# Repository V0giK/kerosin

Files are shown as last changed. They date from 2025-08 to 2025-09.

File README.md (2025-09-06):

# Kerosin – RC Jet Refueling System

&#x20;
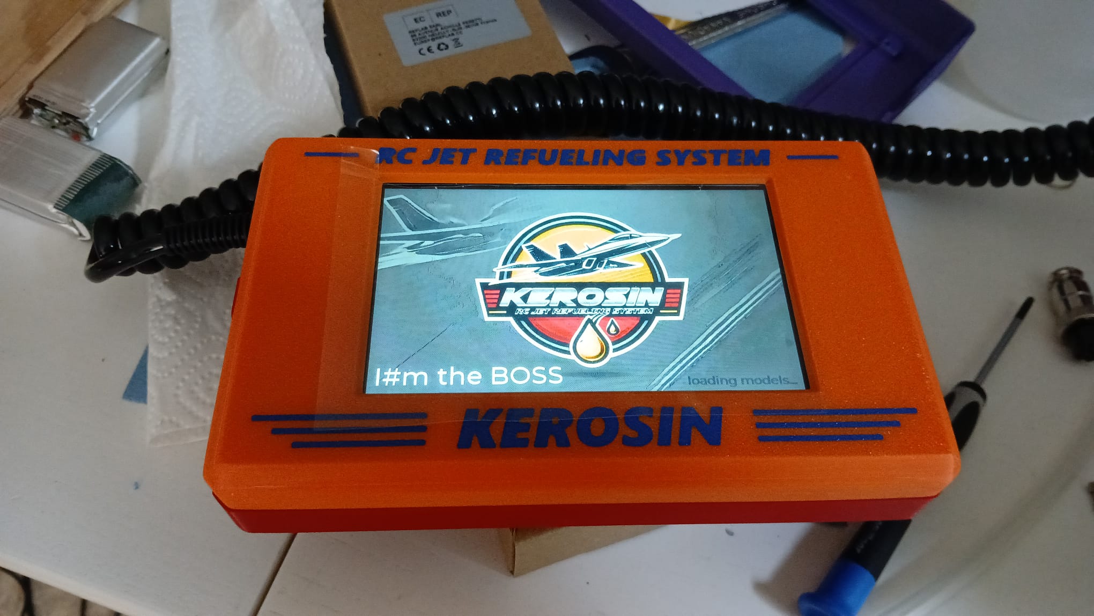
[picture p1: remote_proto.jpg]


---

## ✨ Projektübersicht

**Kerosin – RC Jet Refueling System** ist ein modulares Open-Source-System zur Betankung von Flugmodellen mit Kerosin. Es basiert auf einer Mikrocontroller-Lösung zur Überwachung und Steuerung des Tankvorgangs.

Die Steuerungseinheit ("Controller") befindet sich am Tank. Eine zweite Einheit ("Remote") mit Touchdisplay zeigt Messdaten an und löst Aktionen aus. Die Kommunikation erfolgt über RS-422.

Ziel ist eine robuste und automatisierte komfortabler Bedienung und sicherer Betankung.

---

## 🚀 Features

- **Controller (Arduino Nano)** direkt am Tank
- **Remote (ESP32)** mit Touchdisplay (JC8048W550)
- RS-422 Kommunikation (seriell)
- Automatischer Entleerungsvorgang bei Beuteltanks bei Erreichen des Abschaltdrucks
- Durchflusssensor (YF-S401) zur Kerosinerkennung beim Rückpumpen
- Drucksensor (30 psi, 1/8" NPT) zur Abschaltung
- Konfigurierbare Modelle mit individuell speicherbaren Parametern (Tanktyp, Volumen, Abschaltdruck, usw.)
- Zahnradpumpe für zuverlässige Befüllung und Rückförderung
- 3D-druckbare Komponenten & KiCad-Platinenlayout

---

## 📂 Projektstruktur

```
.
├── software/         # PlatformIO Projekte
│   ├── sTankTeil_Controller/   # Arduino Nano Code
│   └── sTankTeil_Remote/       # ESP32 Touchdisplay
├── kicad/            # KiCad-Schaltplan & Platine
├── 3d/               # 3D-Druckteile (STL, STEP)
├── LICENSE           # GPLv3 Lizenz
└── README.md         # Dieses Dokument
```

---

## 🧱 Komponenten

| Komponente | Beschreibung |
| --- | --- |
| Arduino Nano | Hauptsteuerung (am Tank) |
| ESP32 | Remote-Display (JC8048W550) |
| RS-422 Treiber | Serielle Verbindung Controller ⇄ Remote |
| Drucksensor | 30psi Sensor mit 1/8" NPT Gewinde |
| Durchflusssensor | YF-S401 zur Kerosinerkennung |
| Zahnradpumpe | Elektronisch gesteuert, rückförderfähig |

---

## 🔌 Hardwareaufbau

**Controller** ist direkt am Tank montiert und steuert:

- Drucksensor
- Durchflusssensor
- Zahnradpumpe

**Remote** zeigt Live-Daten über ein kapazitives 5.5" Touchdisplay an und erlaubt:

- Auswahl von Modellspeichern
- Anzeige von Druck, Durchfluss und der Menge des aktuellen Tankvorgangs
- Manuelle Aktionen und Steuerung

Verbindung erfolgt über abgeschirmtes RS-422-Kabel mit serieller Kommunikation.

---

## 📜 Lizenz

Dieses Projekt steht unter der [GNU General Public License v3.0](LICENSE). Jede Quellcodedatei enthält einen entsprechenden Lizenz-Header.

---

## 🤝 Mitmachen & Entwicklung

Pull Requests, Verbesserungsvorschläge oder Erweiterungen sind willkommen. Bei Fragen oder Problemen bitte [Issues](https://github.com/V0giK/kerosin/issues) verwenden.

---

## 🌍 Autor / Projekt

Entwickelt von [V0giK](https://github.com/V0giK) für RC-Tank- & Kerosinsysteme.

---

> „This is not just fuel transfer – it's controlled refueling.“

---

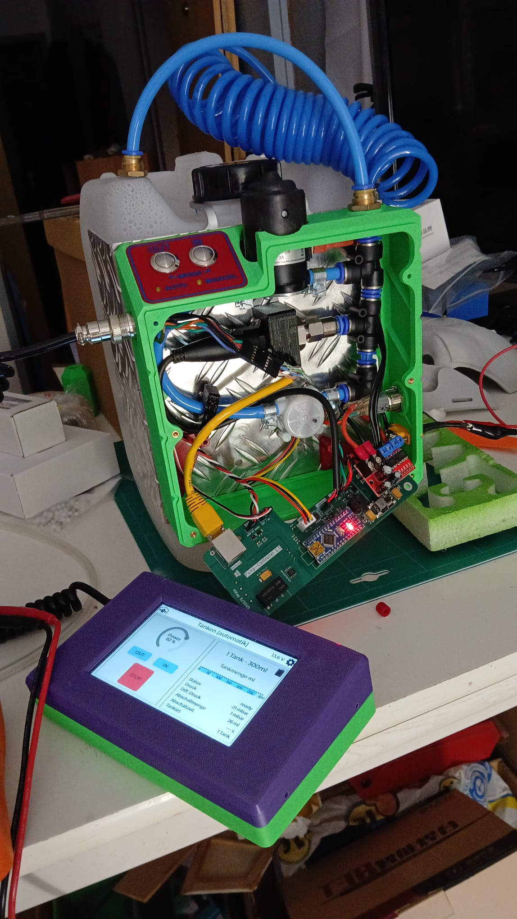
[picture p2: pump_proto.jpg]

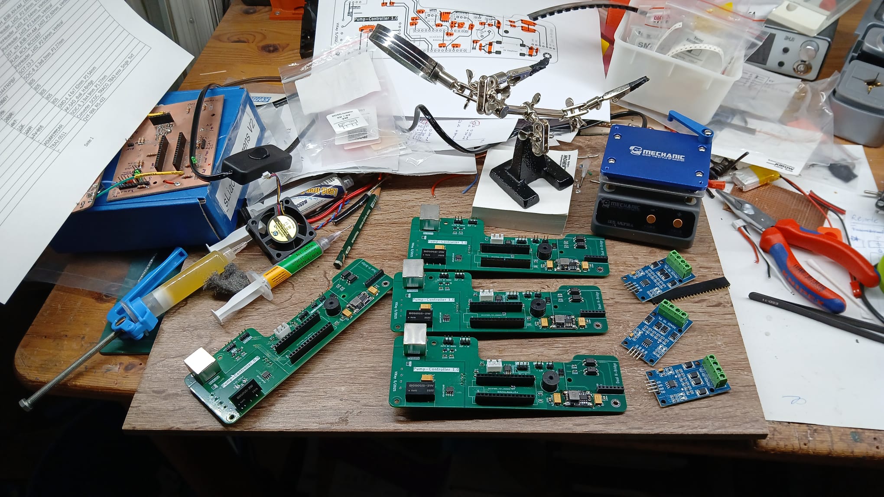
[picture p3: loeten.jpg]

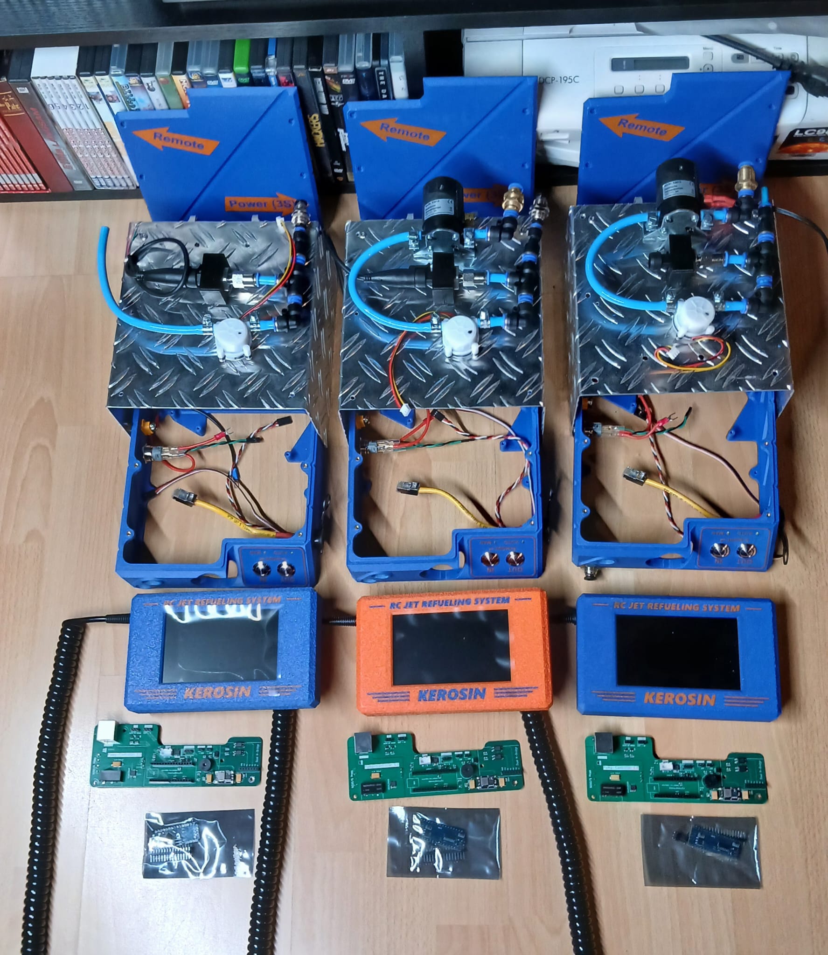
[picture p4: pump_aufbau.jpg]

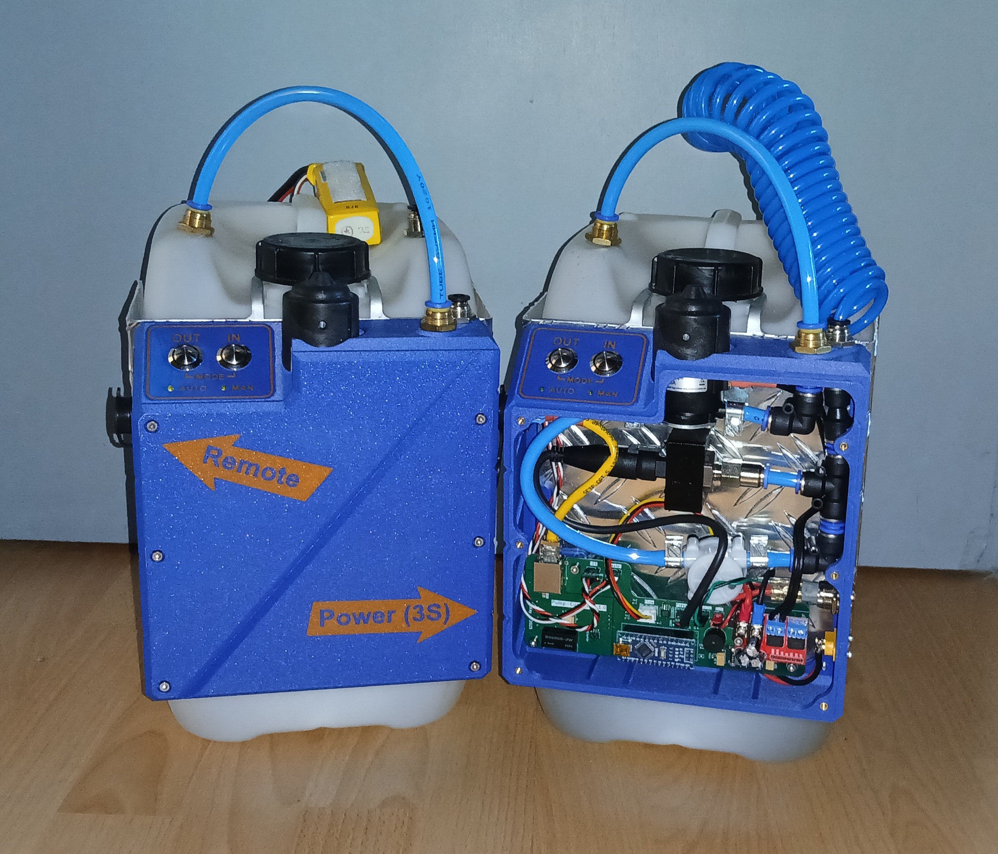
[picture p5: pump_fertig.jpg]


während des bastelns ... https://youtube.com/shorts/paOjxJlpqOs

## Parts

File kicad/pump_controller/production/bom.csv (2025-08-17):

Designator | Footprint | Quantity | Value | LCSC Part #
A1 | Arduino_Nano | 1 | Arduino_Nano_v3.x
BZ1 | Buzzer_12x9.5RM6.7 | 1 | Buzzer
C1 | CP_EIA-7343-31_Kemet-D_Pad2.25x2.55mm_HandSolder | 1 | 16V 150uF
C2, C6 | CP_EIA-7343-31_Kemet-D_Pad2.25x2.55mm_HandSolder | 2 | 6.3V 330uF
C3, C4, C5, C7 | 0805 | 4 | 100n
D3 | D_SMB_Handsoldering | 1 | SMBJ15A
D7 | D_SMA | 1 | SS34
J1 | JST_XH_B3B-XH-AM_1x03_P2.50mm_Vertical | 1 | Flow
J12 | PinHeader_1x02_P2.54mm_Vertical | 1 | LED BattLow
J13 | PinHeader_1x03_P2.54mm_Vertical | 1 | LED auto/manuel
J2 | PinHeader_1x03_P2.54mm_Vertical | 1 | Taster-In/Out
J4 | JST_XH_B3B-XH-AM_1x03_P2.50mm_Vertical | 1 | Pressure
J7 | RJ45_RCH_RC01937 | 1 | RJ45
J9 | PinHeader_1x02_P2.54mm_Vertical | 1 | Batt.
Q1, Q2, Q3, Q4, Q5, Q7 | SOT-23-3 | 6 | IRLML6344TRPBF | IRLML6344TRPBF
Q6 | SOIC-8_5.3x6.2mm_P1.27mm | 1 | SI4435DY
R1 | 0805 | 1 | 18k
R10, R11, R12, R15, R16, R17, R18, R20, R3 | 0805 | 9 | 220R
R13, R14, R5, R6, R7, R8, R9 | 0805 | 7 | 4k7
R19, R2 | 0805 | 2 | 10K
R21, R22, R4 | 0805 | 3 | 100R
U1, U2 | SMD-4_4.6x7.62mm_P2.54mm | 2 | LTV-816
U3 | AK-5AD_dual_H-Bridge | 1 | ~
U5 | SOIC-8_3.9x4.9mm_P1.27mm | 1 | ADuM1201AR
U6 | Converter_DCDC_TRACO_TBA2-xxxx_Single_THT | 1 | TBA2-0511
U7 | QYF-998_RS-422 | 1 | ~

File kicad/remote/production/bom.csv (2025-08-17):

Designator | Footprint | Quantity | Value | LCSC Part #
C1 | CP_EIA-7343-31_Kemet-D_Pad2.25x2.55mm_HandSolder | 1 | 16V 150uF
C5 | 0805 | 1 | 100n
C6 | CP_EIA-7343-31_Kemet-D_Pad2.25x2.55mm_HandSolder | 1 | 6.3V 330uF
D1 | D_SMA | 1 | SS34
D3 | D_SMB_Handsoldering | 1 | SMBJ15A
J1 | PinHeader_1x02_P2.54mm_Vertical | 1 | 5V
J2 | MPX_Adapter_small_6Pol | 1 | MPX Kabel
J3 | PinHeader_1x04_P2.54mm_Vertical | 1 | Conn_01x04_Pin
R1, R3 | R_Axial_DIN0207_L6.3mm_D2.5mm_P10.16mm_Horizontal | 2 | 10k
R2 | R_Axial_DIN0207_L6.3mm_D2.5mm_P10.16mm_Horizontal | 1 | 4k7
U1 | LevelConversion_TXB0108 | 1 | LevelConverter
U6 | TBA2-xxxx_liegend | 1 | TBA2-0511
U7 | QYF-998_RS-422 | 1 | ~

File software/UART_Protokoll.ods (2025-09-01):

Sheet: UART Action IDs
S<R/W>:<ID>:<WERT>:<CRC>
Konstante | ID |  | Wert
COM_ID_TYPE | 1 | Geräte Typ – nur lesen aus Nano (EEPROM oder #define im Code - NANO) | 1=Pumpe, 2=was anderes
COM_ID_FLOW_TICKS | 2 | Flow Ticks/Liter (EEPROM) | [1...99999]
COM_ID_PRESSURE_AVG | 3 | Anzahl Messwerte für Mittelwert Drucksensor (EEPROM) | [1...90]
COM_ID_AKKU_MIN | 4 | Akku minimal Spannung (EEPROM) | [100...119]
COM_ID_AKKU_CALIB | 5 | Akku Kalibrierfaktor (EEPROM)
COM_ID_BEEP | 6 | Signalton/Beep (EEPROM) | [0, 1]
COM_ID_SYSTEM_OFF | 7 | Systemabschaltung in Sekunden (EEPROM) | [60…550]
COM_ID_PWR_MANUEL | 8 | Pumpleistung manueller Betrieb (EEPROM) | [40…100]
COM_ID_PUMP_PWR | 9 | Pumpleistung aktuell | [40…100]
COM_ID_MAX_REFUEL_TIME | 10 | max. Betankungszeit in Sekunden | [0...350]
COM_ID_MAX_DEFUEL_TIME | 11 | max. Enttankungszeit in Sekunden | [0...350]
COM_ID_BACK_FUEL_TIME | 12 | Rücktankzeit in Sekunden | [0…60]
COM_ID_AIR_REMOVAL_TIME | 13 | Luftblasenentfernung in Sekunden | [0...30]
COM_ID_PUMP_STOP_EMPTY_DELAY | 14 | Abschaltzeit nach Leererkennung in Sekunden | [0...30]
COM_ID_MESSUREMENT_DELAY | 15 | Messverzögerung in Sekunden | [0...30]
COM_ID_MAX_REFUEL_ML | 16 | max. Tankmenge in Milliliter | [0...20990]
COM_ID_MAX_DEFUEL_ML | 17 | max. Enttankmenge in Milliliter | [0...20990]
COM_ID_MAX_PRESSURE | 18 | max. Befülldruck in mbar | [0...4990]
COM_ID_PUMP_STOP_PRESSURE_DIFF | 19 | Differenzabschaltdruck in mbar | [0...255]
COM_ID_PUMP_STOP_PRESSURE_EMPTY | 20 | Leerlaufabschaltdruck mbar | [0...255]
COM_ID_HOPPER_PRESSURE | 21 | Hopperfülldruck in mbar | [0...4990]
COM_ID_PUMP_STOP_HOPPER_PRESSURE_DIFF | 22 | Differenzabschaltdruck Hopper in mbar | [0...255]
COM_ID_PRESSURE_DROP_HOSE_BREAK | 23 | Druckabfall bei Schlauchbruch in mbar (0=Aus) | [0...255] 0=Aus
COM_ID_MODELNAME | 24 | Modellname | 15 Zeichen, es werden max 15 Zeichen in EEPROM übertragen
COM_ID_SAVE_MODEL_EEPROM | 29 | Modelldaten in EEPROM schreiben für Verwendung ohne Remote | ‘5‘ als Value immer 5 mitgeben
COM_ID_STATUS | 30 | Status | Ready, Tanken, Entlüften, …
COM_ID_CURRENT_ML | 31 | Momentane Tankmenge in Milliliter
COM_ID_CURRENT_MBAR | 32 | Momentaner Tankdruck in mbar
COM_ID_CURRENT_DIFF_MBAR | 33 | Differenzdruck in mbar
COM_ID_AKKU_VOLT | 34 | Akkuspannung | beim senden als Kallibrierungsspannung an Controller 1111 = 11.11
COM_ID_PUMP_CONTROL | 40 | Pumpe steuern | [0...2] 0=Enttanken, 1=Tanken, 2=STOP
COM_ID_WRITE_EEPROM | 41 | Controller – Daten in EEPROM schreiben (EEPROM) | ‘5‘ als Value immer 5 mitgeben
COM_ID_PUMP_MODE | 42 | Pumpen Mode | [0...2] 0=manuell, 1=auto, 2=kalib. Flow, 3=kalib. Model
COM_ID_FLOWCALIBRATE | 43 | aktuelle Flowticks seit letztem Reset | [0...99999]
COM_ID_TANKTYPE | 44 | Tanktyp | [0...2] 0=Beutel, 1=1 Tank, 2=2 Tanks
COM_ID_BROADCAST | 45 | Daten per Broadcast senden (dauernd) | [0...1] 0=nein, 1=ja
COM_ID_FIRMWARE_VERSION | 46 | Firmware Version abfragen | 1.0.0‘
COM_ID_MC_RESET | 99 | Mikrocontroller reset | 99=DeepSleep

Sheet: Button IDs
Button Ids
ID | Button | Panel (Screen)
1 | Reset | Flowsensor kalibrierung | BTN_FLOW_RESET
2 | Set – Flow | Flowsensor kalibrierung | BTN_FLOW_SET
3 | Reset | Modell – Anzahl Tankvorgänge | BTN_MODEL_RESET_TANKCOUNT
4 | Reset | Modell – Gesamtmenge | BTN_MODEL_RESET_TOTAL
5 | Modell löschen | Modell – löschen | BTN_MODEL_DELETE
6 | Modell speichern JA | Modelle – neu/bearbeiten | BTN_MODEL_SAVE_YES
7 | Modell speichern NEIN | Modelle – neu/bearbeiten | BTN_MODEL_SAVE_NO
8 | System speichern JA | Systemeinstellungen bearbeiten | BTN_SYSTEM_SAVE_YES
9 | System speichern NEIN | Systemeinstellungen bearbeiten | BTN_SYSTEM_SAVE_NO
10 | Save Modeldata in Controller | Modell – Tanken/Pumpen | BTN_MODEL_SAVE2CONTROLLER
11 | Header-Titel longPress |  | BTN_HEADER_TITEL_LONGPRESS
12 | Stop Snake |  | BTN_SNAKE_STOP
13 | Tanktype geändert | Modell – Settings | BTN_MODEL_TYPE_CHG
14 | gemessene Spannung senden | Systemeinstellungen bearbeiten | BTN_SYSTEM_SEND_CALIBVOLT
15 | WiFi starten (Backup/OTA) | Systemeinstellungen bearbeiten | BTN_SYSTEM_BACKUP

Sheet: Nano Pins
NANO Pins
PIN | Verwendung |  | Pull-Up/Down
A0 | Batt. Spannung messen
A1 | LED model |  | Pull-up | 4,7 kΩ
A2 | LED manuel |  | Pull-up | 4,7 kΩ
A3 | LED Batt. Low |  | Pull-up | 4,7 kΩ
A4 | SDA | I2C | Pull-up | 4,7 kΩ
A5 | SCL | I2C | Pull-up | 4,7 kΩ
A6 | Druck Sensor |  | Pull-down | 4,7 kΩ
A7
D2 | Flow Sensor |  | Pull-up | 4,7 kΩ
D3 | LED ERROR | PWM | Pull-up | 4,7 kΩ
D4 | Buzzer
D5 | H-Bridge D2 | PWM
D6 | H-Bridge D3 | PWM
D7 | Taster-In |  | Pull-up | 4,7 kΩ
D8 | Taster-Out |  | Pull-up | 4,7 kΩ
D9 |  | PWM
D10 | SoftSerial TX | PWM | Pull-up
D11 | SoftSerial RX | PWM | Pull-up
D12 | remote check |  | Pull-up | 4,7 kΩ
D13 | ready LED | Built-in LED | Pull-up | ?

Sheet: Modell Parameter
 |  |  |  | Tanktyp
Konstante | Hide Variable | Beschreibung | Default | Beutel | 1 Tank | 2Tanks
COM_ID_MODELNAME | bHideModModelname | Modell |  | X | X | X
COM_ID_TANKTYPE |  | Tanktyp | 0 = Beutel | X | X | X
COM_ID_PUMP_PWR |  | Pumpleistung [%] | 81 | X | X | X
COM_ID_PRESSURE_DROP_HOSE_BREAK |  | Druckabfall bei Schlauchbruch [mbar] (0=Aus) | 0 | X | X | X | 0 = deaktiviert
COM_ID_MAX_REFUEL_TIME |  | Maximale Betankzeit [s] | 240 | X | X | X | 0 = deaktiviert
COM_ID_MAX_DEFUEL_TIME |  | Maximale Enttankzeit [s] | 240 | X | X | X | 0 = deaktiviert
COM_ID_BACK_FUEL_TIME |  | Rücktankzeit [s] | 6 | X | X | X | 0 = deaktiviert
COM_ID_AIR_REMOVAL_TIME |  | Luftblasenentfernung [s] | 15 | X Nachdem Unterdruck > Leerlaufabschaltdruck |  |  | 0 = deaktiviert
COM_ID_PUMP_STOP_EMPTY_DELAY |  | Abschaltzeit nach Leererkennung [s] | 5 (Beutel bei Speicher auf 0) |  | X | X | 0 = deaktiviert
COM_ID_MESSUREMENT_DELAY |  | Messverzögerung [s] | 5 | X | X | X | 0 = deaktiviert
COM_ID_MAX_REFUEL_ML |  | Maximale Betankmenge [ml] | 500 | X | X | X | 0 = deaktiviert
COM_ID_MAX_DEFUEL_ML |  | Maximale Enttankmenge [ml] | 500 | X | X | X | 0 = deaktiviert
COM_ID_MAX_PRESSURE |  | Maximaler Tankdruck [mbar] | 350 | X | X | X | 0 = deaktiviert
COM_ID_PUMP_STOP_PRESSURE_DIFF |  | Differenzabschaltdruck [mbar] | 19 |  | X | X | 0 = deaktiviert
COM_ID_PUMP_STOP_PRESSURE_EMPTY |  | Leerlaufabschaltdruck [mbar] | 187 | X Unterdruck < Leerlaufdruck DiffDruck == 0 FlowRate <= 1 ml/s | X | X | 0 = deaktiviert
COM_ID_HOPPER_PRESSURE |  | Maximaler Hopperfülldruck [mbar] | 400 |  |  | X | 0 = deaktiviert
COM_ID_PUMP_STOP_HOPPER_PRESSURE_DIFF |  | Differenzabschaltdruck Hopper [mbar] | 19 |  |  | X | 0 = deaktiviert
 |  | Letzte Tankmege [ml] | 0 | X | X | X
 |  | Tankvorgänge | 0 | X | X | X
 |  | Gesamttankmenge [L] | 0 | X | X | X

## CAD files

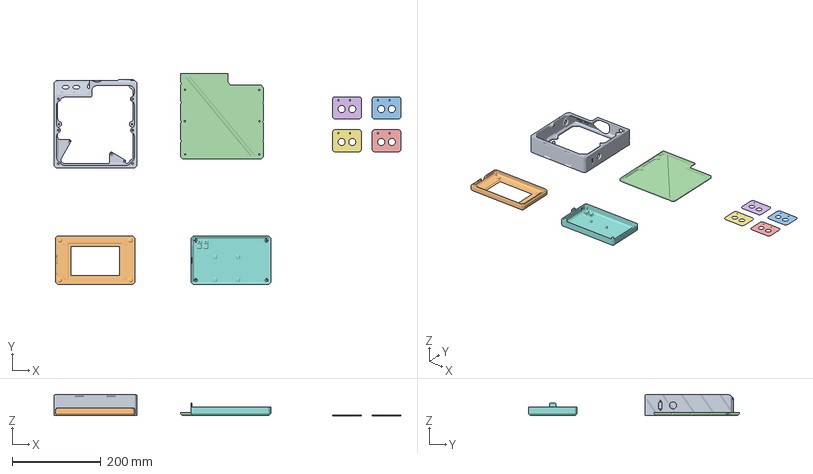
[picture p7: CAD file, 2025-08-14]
3d/Gehäuse_Pumpe v5.3mf
784.2 x 476.9 x 48.5 mm
Gehäuse_Frame.stl
Remote_Deckel.stl
Panel.stl x 4
Gehäuse_Deckel.stl
Remote_Boden.stl

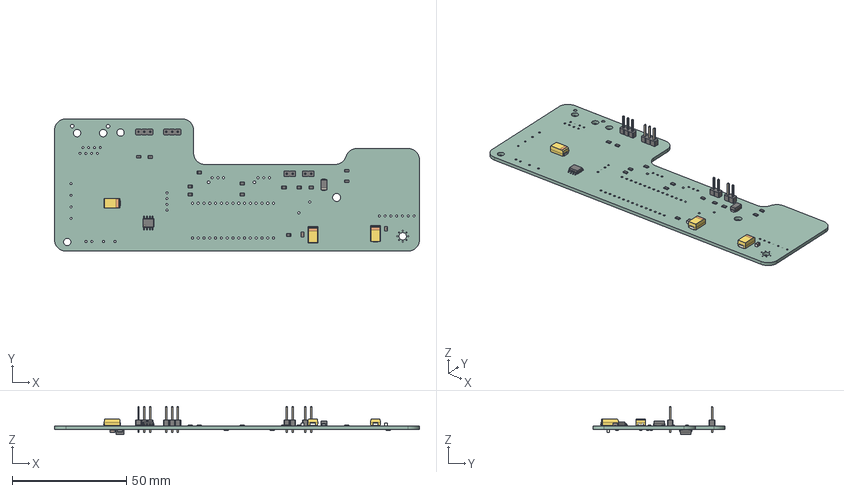
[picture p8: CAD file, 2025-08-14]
kicad/pump_controller/pump_controller.step
160.0 x 58.0 x 12.4 mm
PinHeader_1x02_P2.54mm_Vertical x 2
PinHeader_1x03_P2.54mm_Vertical x 2
R_0805_2012Metric x 17
SOIC-8_3.9x4.9mm_P1.27mm
CP_EIA-7343-31_Kemet-D x 3
C_0805_2012Metric x 3
D_SMA
D_SMB
pump_controller_PCB

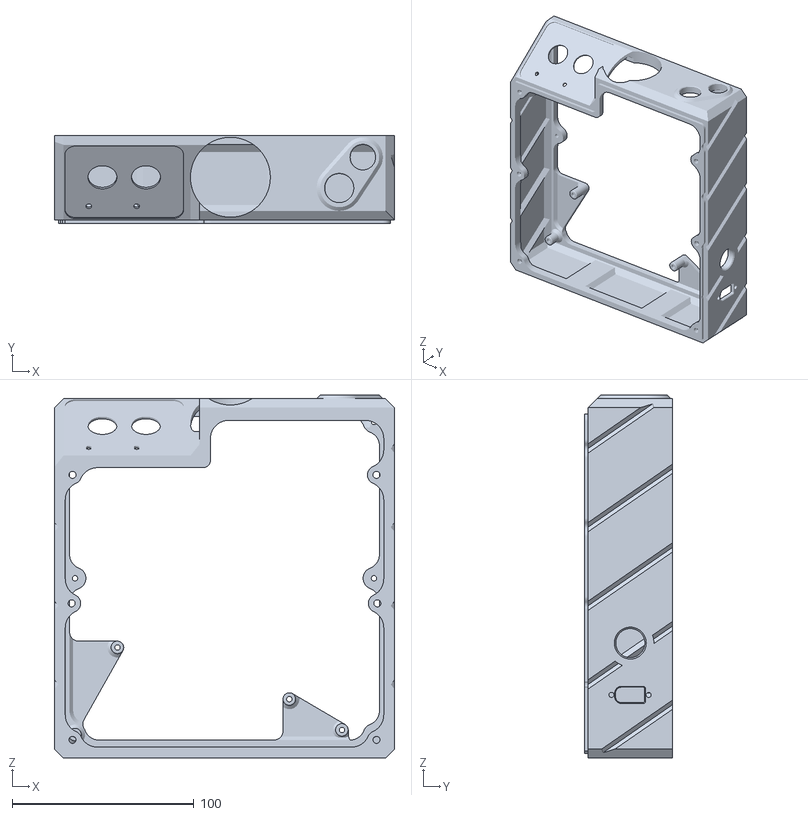
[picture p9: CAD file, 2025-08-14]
3d/Gehäuse_Frame.stl
187.5 x 48.5 x 200.0

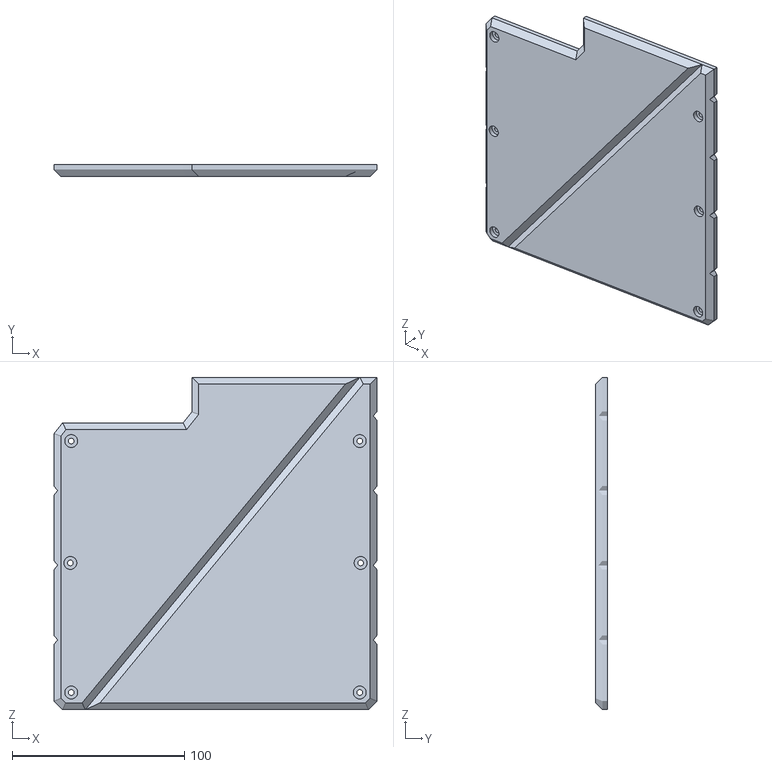
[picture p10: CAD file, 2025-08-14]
3d/Gehäuse_Deckel.stl
187.5 x 7.00 x 193.0

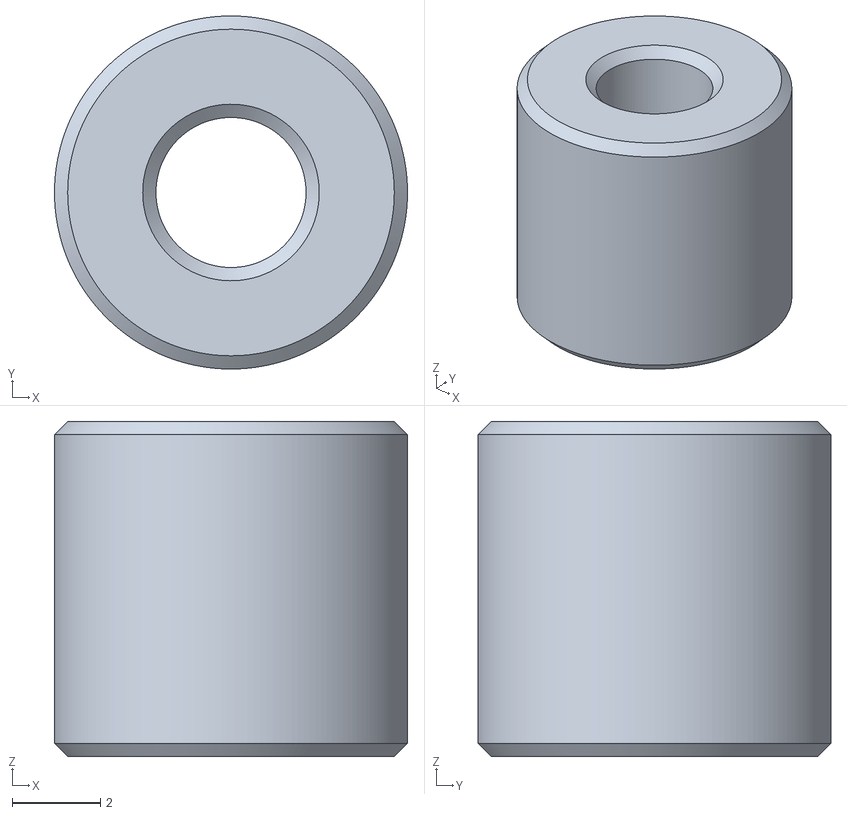
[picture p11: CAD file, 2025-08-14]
3d/Huelse.stl
8.00 x 8.00 x 7.60

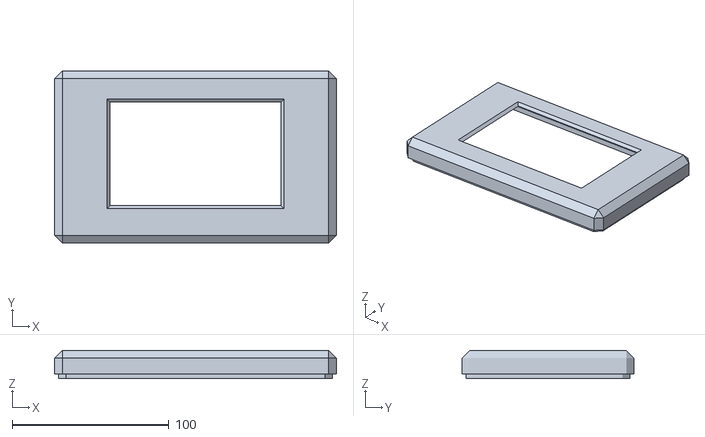
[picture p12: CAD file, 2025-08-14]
3d/Remote_Deckel.stl
180.0 x 110.0 x 18.0

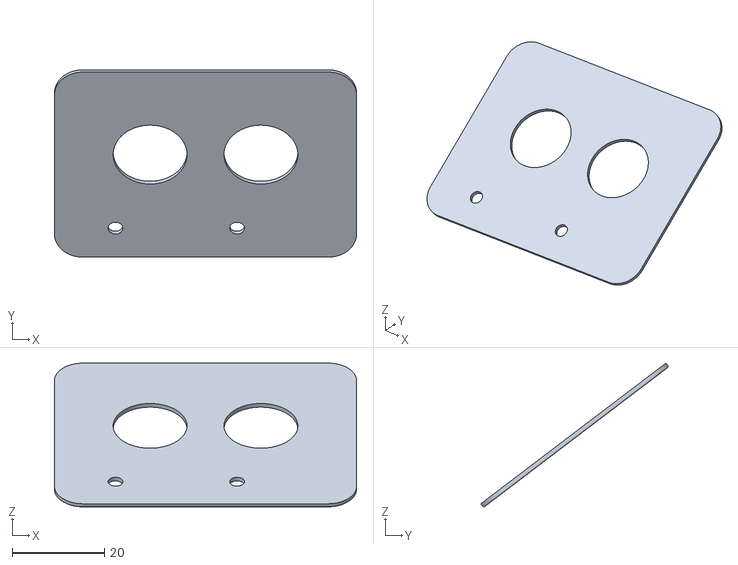
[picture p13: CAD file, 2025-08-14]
3d/Panel.stl
65.4 x 40.6 x 31.1

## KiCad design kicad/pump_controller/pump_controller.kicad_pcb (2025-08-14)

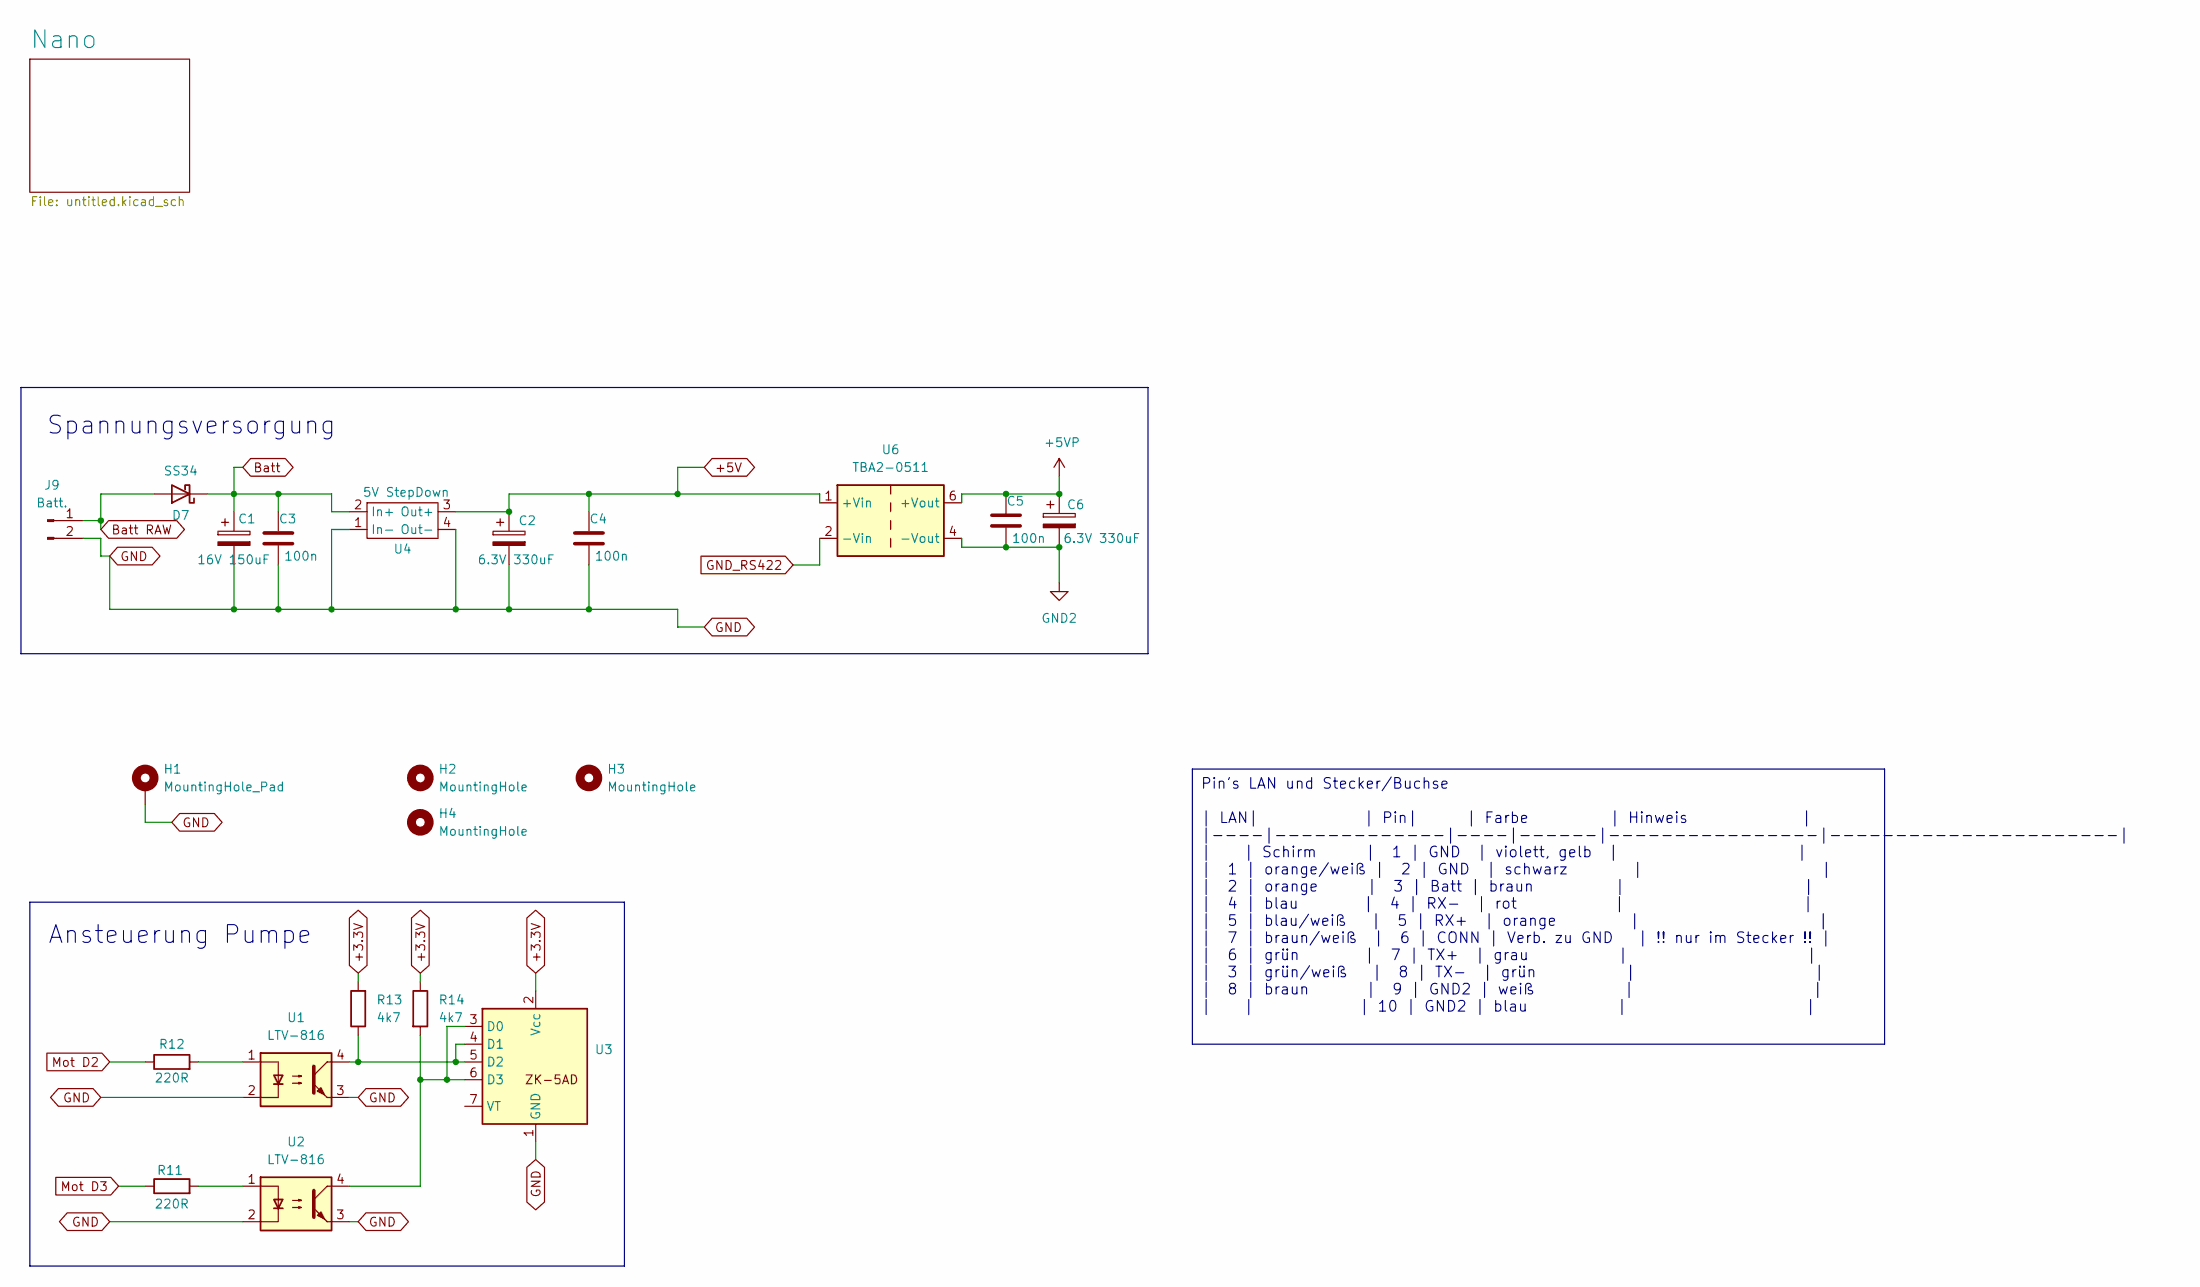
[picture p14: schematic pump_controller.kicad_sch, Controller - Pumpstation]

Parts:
C1: 16V 150uF; CP_EIA-7343-31_Kemet-D_Pad2.25x2.55mm_HandSolder
C2, C6: 6.3V 330uF; CP_EIA-7343-31_Kemet-D_Pad2.25x2.55mm_HandSolder
C3, C4, C5: 100n; C_0805_2012Metric_Pad1.18x1.45mm_HandSolder
D7: SS34; D_SMA
H1: MountingHole_Pad; MountingHole_3.2mm_M3_Pad_Via
H2, H4: MountingHole; MountingHole_3.2mm_M3_ISO7380
H3: MountingHole; MountingHole_3.5mm
J9: Batt.; PinHeader_1x02_P2.54mm_Vertical
R11, R12: 220R; R_0805_2012Metric_Pad1.20x1.40mm_HandSolder
R13, R14: 4k7; R_0805_2012Metric_Pad1.20x1.40mm_HandSolder
U1, U2: LTV-816; SMD-4_4.6x7.62mm_P2.54mm
U3: AK-5AD_dual_H-Bridge
U4: 5V StepDown; Step-Down 5V
U6: TBA2-0511; Converter_DCDC_TRACO_TBA2-xxxx_Single_THT

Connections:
+3.3V: R13.2, R14.1, U3.2 (Vcc)
+5V: C2.1, C4.1, U4.3 (Out+), U6.1 (+Vin); also elsewhere on the board
+5VP: C5.1, C6.1, U6.6 (+Vout); also elsewhere on the board
Batt: C1.1, C3.1, D7.1 (K), U4.2 (In+); also elsewhere on the board
Batt RAW: D7.2 (A), J9.1
GND: C1.2, C2.2, C3.2, C4.2, H1.1, J9.2, U1.2, U1.3, U2.2, U2.3, U3.1 (GND), U4.1 (In-), U4.4 (Out-); also elsewhere on the board
GND2: C5.2, C6.2, U6.4 (-Vout); also elsewhere on the board
GND_RS422: U6.2 (-Vin); also elsewhere on the board
Mot D2: R12.1; also elsewhere on the board
Mot D3: R11.1; also elsewhere on the board
unnamed: R11.2, U2.1
unnamed: R12.2, U1.1
unnamed: R14.2, U2.4, U3.3 (D0), U3.6 (D3)
unnamed: R13.1, U1.4, U3.4 (D1), U3.5 (D2)

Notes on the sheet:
Spannungsversorgung
Ansteuerung Pumpe
Pin's LAN und Stecker/Buchse | LAN| | Pin| | Farbe | Hinweis | |----|-------------|----|------|----------------|----------------------| | | Schirm | 1 | GND | violett, gelb | | | 1 | orange/weiß | 2 | GND | schwarz | | | 2 | orange | 3 | Batt | braun | | | 4 | blau | 4 | RX- | rot | | | 5 | blau/we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

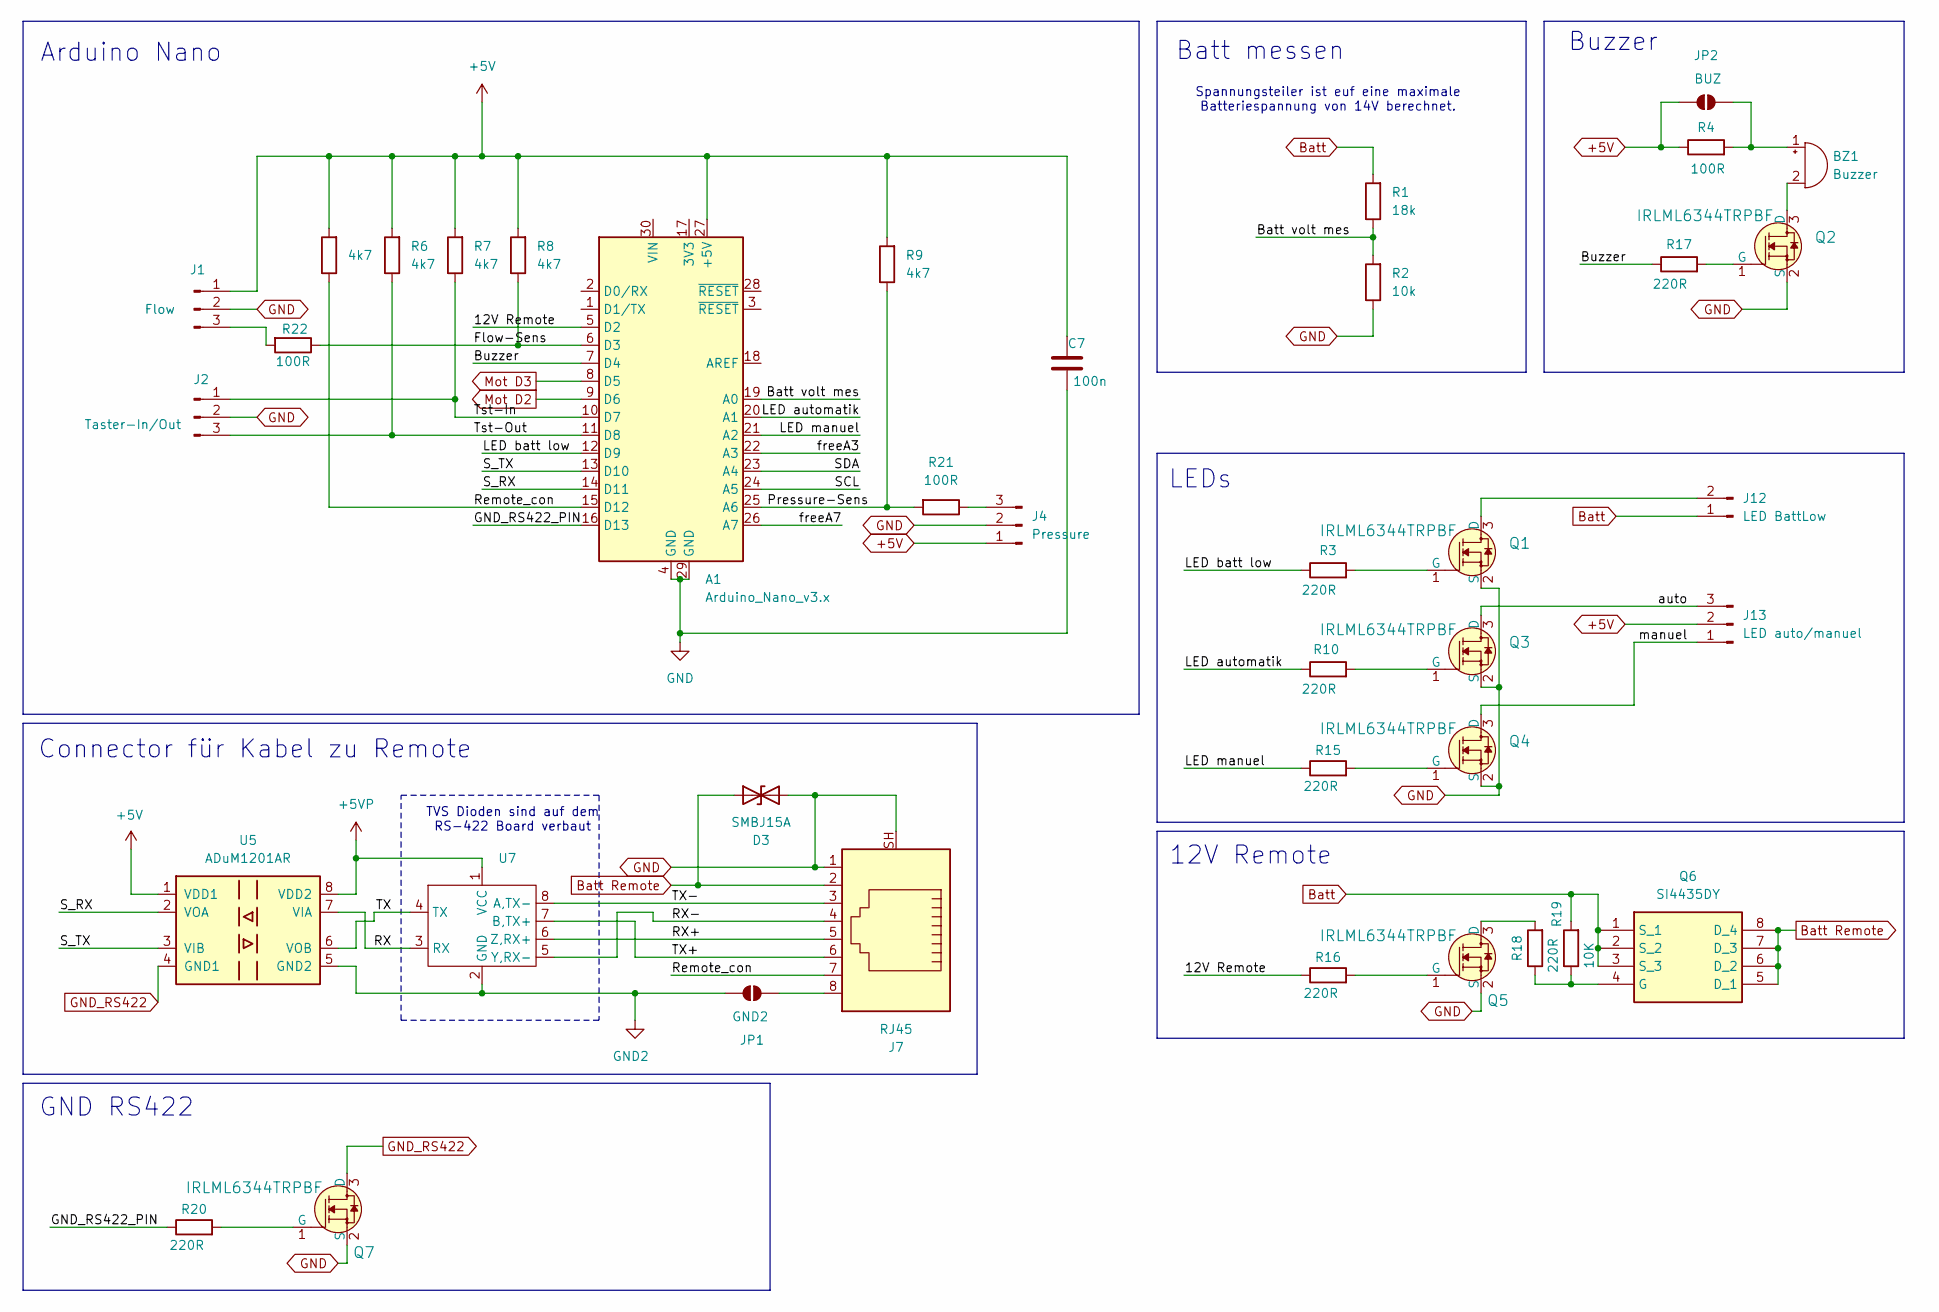
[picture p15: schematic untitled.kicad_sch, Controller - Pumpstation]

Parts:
A1: Arduino_Nano_v3.x; Arduino_Nano
BZ1: Buzzer; Buzzer_12x9.5RM6.7
C7: 100n; C_0805_2012Metric_Pad1.18x1.45mm_HandSolder
D3: SMBJ15A; D_SMB_Handsoldering
J1: Flow; JST_XH_B3B-XH-AM_1x03_P2.50mm_Vertical
J2: Taster-In/Out; PinHeader_1x03_P2.54mm_Vertical
J4: Pressure; JST_XH_B3B-XH-AM_1x03_P2.50mm_Vertical
J7: RJ45; RJ45_RCH_RC01937
J12: LED BattLow; PinHeader_1x02_P2.54mm_Vertical
J13: LED auto/manuel; PinHeader_1x03_P2.54mm_Vertical
JP1: GND2; SolderJumper-2_P1.3mm_Open_Pad1.0x1.5mm
JP2: BUZ; SolderJumper-2_P1.3mm_Open_Pad1.0x1.5mm
Q1, Q2, Q3, Q4, Q5, Q7: IRLML6344TRPBF; SOT-23-3; MPN IRLML6344TRPBF; Digi-Key_PN IRLML6344TRPBFCT-ND
Q6: SI4435DY; SOIC-8_5.3x6.2mm_P1.27mm; Mouser Part Number 512-SI4435DY
R1: 18k; R_0805_2012Metric_Pad1.20x1.40mm_HandSolder
R2: 10k; R_0805_2012Metric_Pad1.20x1.40mm_HandSolder
R3, R10, R15, R16, R17, R18, R20: 220R; R_0805_2012Metric_Pad1.20x1.40mm_HandSolder
R4, R21, R22: 100R; R_0805_2012Metric_Pad1.20x1.40mm_HandSolder
R5, R6, R7, R8, R9: 4k7; R_0805_2012Metric_Pad1.20x1.40mm_HandSolder
R19: 10K; R_0805_2012Metric_Pad1.20x1.40mm_HandSolder
U5: ADuM1201AR; SOIC-8_3.9x4.9mm_P1.27mm
U7: QYF-998_RS-422

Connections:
+5V: A1.27 (+5V), C7.1, J1.1, J4.1, J13.2, JP2.2 (B), R4.1, R5.2, R6.2, R7.2, R8.2, R9.2, U5.1 (VDD1); also elsewhere on the board
+5VP: U5.8 (VDD2), U7.1 (VCC); also elsewhere on the board
/Nano/12V Remote: A1.5 (D2), R16.1
/Nano/Batt volt mes: A1.19 (A0), R1.1, R2.2
/Nano/Buzzer: A1.7 (D4), R17.1
/Nano/Flow-Sens: A1.6 (D3), R8.1, R22.1
/Nano/GND_RS422_PIN: A1.16 (D13), R20.1
/Nano/LED automatik: A1.20 (A1), R10.1
/Nano/LED batt low: A1.12 (D9), R3.1
/Nano/LED manuel: A1.21 (A2), R15.1
/Nano/Pressure-Sens: A1.25 (A6), R9.1, R21.2
/Nano/RX: U5.7 (VIA), U7.3 (RX)
/Nano/RX+: J7.4, U7.5 (Y)
/Nano/RX-: J7.5, U7.6 (Z)
/Nano/Remote_con: A1.15 (D12), J7.7, R5.1
/Nano/SCL: A1.24 (A5)
/Nano/SDA: A1.23 (A4)
/Nano/S_RX: A1.14 (D11), U5.2 (VOA)
/Nano/S_TX: A1.13 (D10), U5.3 (VIB)
/Nano/TX: U5.6 (VOB), U7.4 (TX)
/Nano/TX+: J7.6, U7.7 (B)
/Nano/TX-: J7.3, U7.8 (A)
/Nano/Tst-In: A1.10 (D7), J2.1, R7.1
/Nano/Tst-Out: A1.11 (D8), J2.3, R6.1
/Nano/auto: J13.3, Q3.3 (D)
/Nano/freeA3: A1.22 (A3)
/Nano/freeA7: A1.26 (A7)
/Nano/manuel: J13.1, Q4.3 (D)
Batt: J12.1, Q6.1 (S_1), Q6.2 (S_2), Q6.3 (S_3), R1.2, R19.2; also elsewhere on the board
Batt Remote: D3.1 (A1), J7.2, Q6.5 (D_1), Q6.6 (D_2), Q6.7 (D_3), Q6.8 (D_4)
GND: A1.4 (GND), A1.29 (GND), C7.2, D3.2 (A2), J1.2, J2.2, J4.2, J7.1, J7.SH, Q1.2 (S), Q2.2 (S), Q3.2 (S), Q4.2 (S), Q5.2 (S), Q7.2 (S), R2.1; also elsewhere on the board
GND2: JP1.1 (A), U5.5 (GND2), U7.2 (GND); also elsewhere on the board
GND_RS422: Q7.3 (D), U5.4 (GND1); also elsewhere on the board
Mot D2: A1.9 (D6); also elsewhere on the board
Mot D3: A1.8 (D5); also elsewhere on the board
unnamed: BZ1.1 (+), JP2.1 (A), R4.2
unnamed: BZ1.2 (-), Q2.3 (D)
unnamed: J1.3, R22.2
unnamed: J4.3, R21.1
unnamed: J12.2, Q1.3 (D)
unnamed: J7.8, JP1.2 (B)
unnamed: Q1.1 (G), R3.2
unnamed: Q2.1 (G), R17.2
unnamed: Q3.1 (G), R10.2
unnamed: Q4.1 (G), R15.2
unnamed: Q5.3 (D), R18.2
unnamed: Q5.1 (G), R16.2
unnamed: Q6.4 (G), R18.1, R19.1
unnamed: Q7.1 (G), R20.2

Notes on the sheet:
Buzzer
GND RS422
12V Remote
LEDs
Spannungsteiler ist euf eine maximale Batteriespannung von 14V berechnet.
TVS Dioden sind auf dem RS-422 Board verbaut
Batt messen
Arduino Nano
Connector für Kabel zu Remote

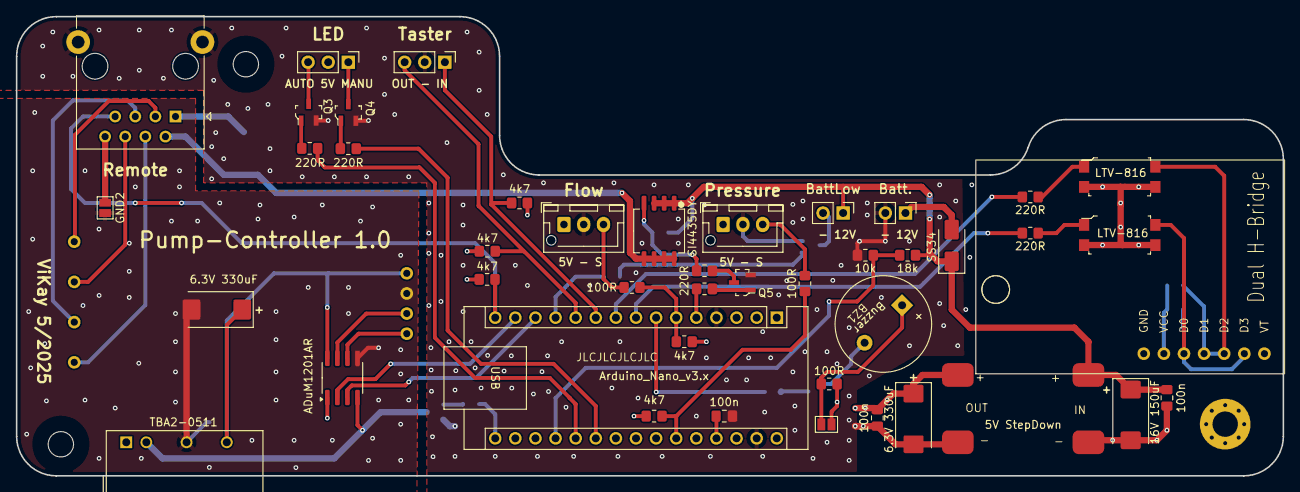
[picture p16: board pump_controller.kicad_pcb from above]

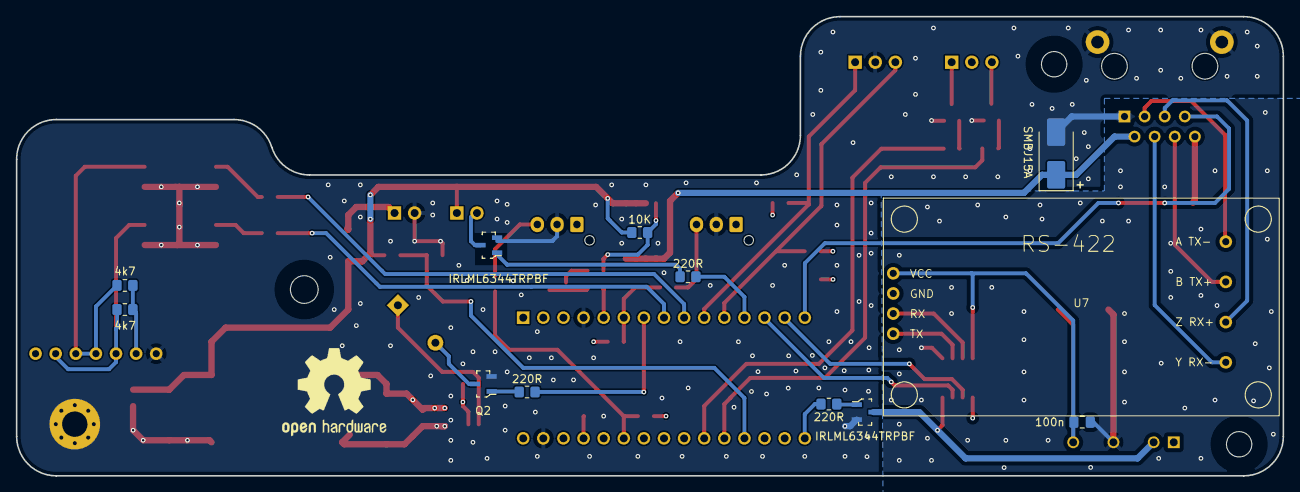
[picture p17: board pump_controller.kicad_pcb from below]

Board: 4 copper layers, 160.0 x 58.0 mm, 60 parts (12 on the bottom side), 51 nets.

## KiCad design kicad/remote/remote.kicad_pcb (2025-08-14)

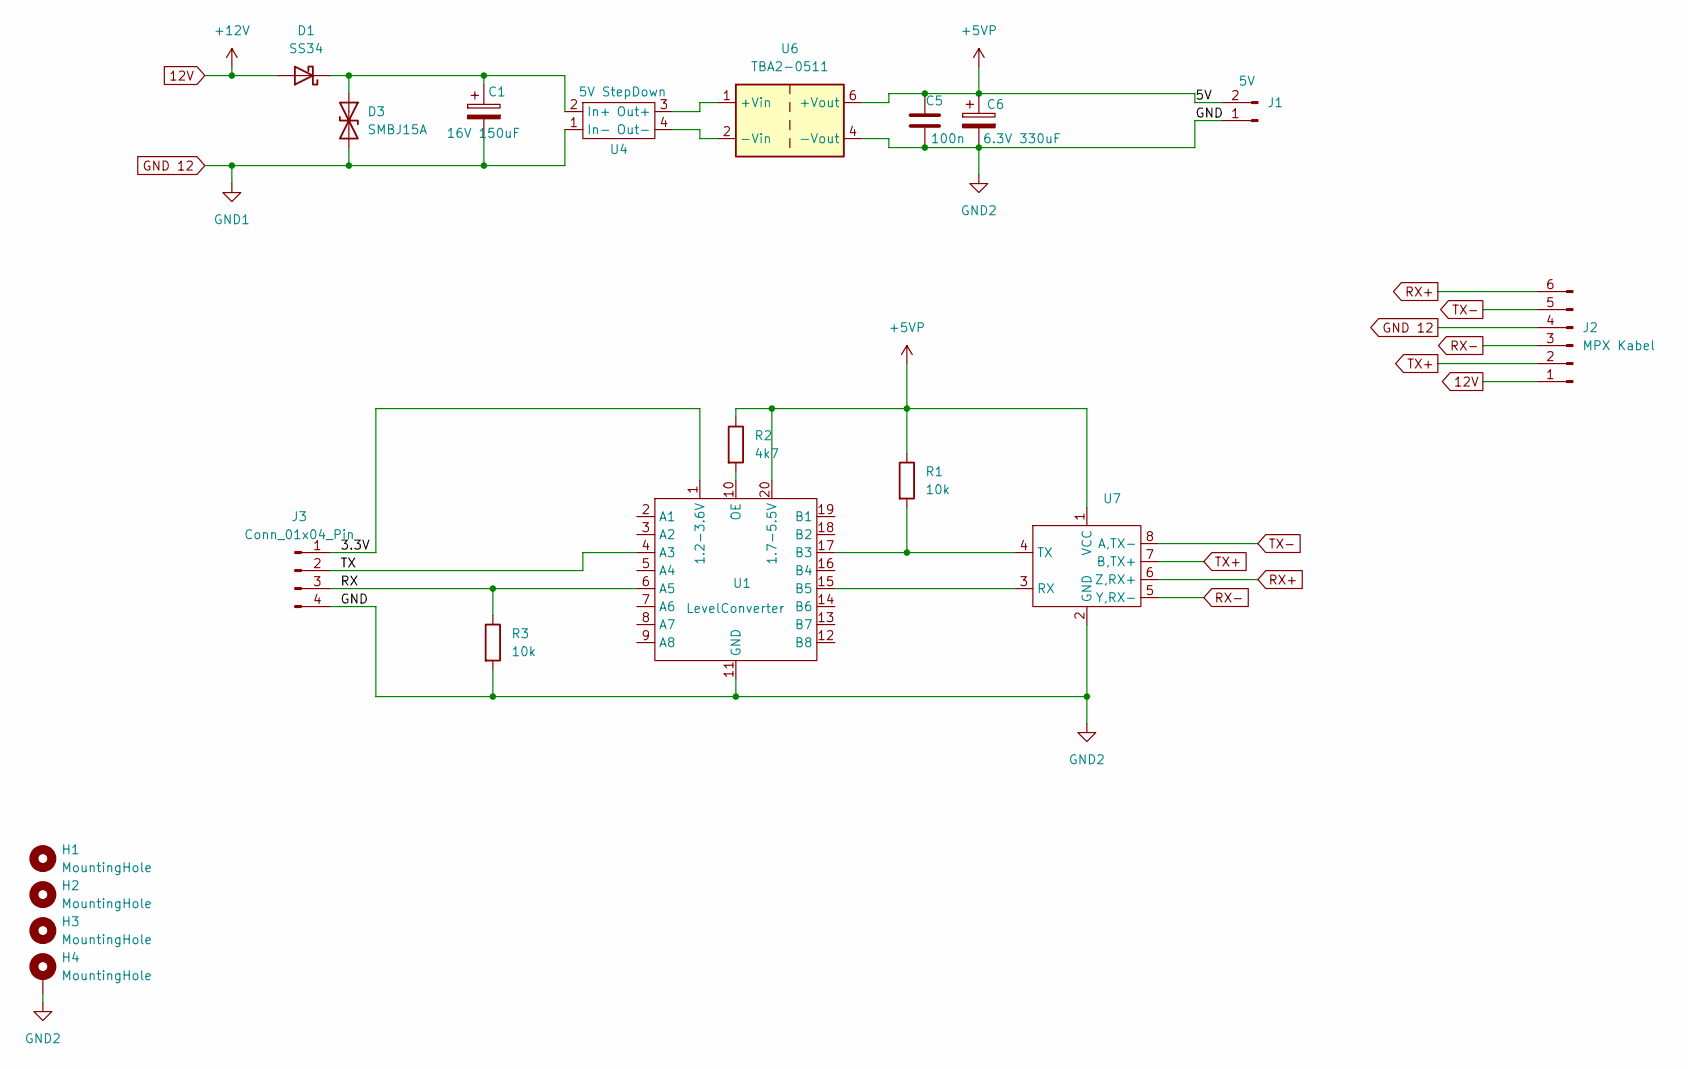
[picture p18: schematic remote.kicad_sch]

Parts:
C1: 16V 150uF; CP_EIA-7343-31_Kemet-D_Pad2.25x2.55mm_HandSolder
C5: 100n; C_0805_2012Metric_Pad1.18x1.45mm_HandSolder
C6: 6.3V 330uF; CP_EIA-7343-31_Kemet-D_Pad2.25x2.55mm_HandSolder
D1: SS34; D_SMA
D3: SMBJ15A; D_SMB_Handsoldering
H1, H2, H3: MountingHole; MountingHole_3.2mm_M3_ISO7380
H4: MountingHole; MountingHole_3.2mm_M3_Pad_Via
J1: 5V; PinHeader_1x02_P2.54mm_Vertical
J2: MPX Kabel; MPX_Adapter_small_6Pol
J3: Conn_01x04_Pin; PinHeader_1x04_P2.54mm_Vertical
R1, R3: 10k; R_Axial_DIN0207_L6.3mm_D2.5mm_P10.16mm_Horizontal
R2: 4k7; R_Axial_DIN0207_L6.3mm_D2.5mm_P10.16mm_Horizontal
U1: LevelConverter; LevelConversion_TXB0108
U4: 5V StepDown; Step-Down 5V
U6: TBA2-0511; TBA2-xxxx_liegend
U7: QYF-998_RS-422

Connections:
12V: D1.2 (A), J2.1
+5VP: C5.1, C6.1, J1.2, R1.1, R2.1, U1.20 (1.7-5.5V), U6.6 (+Vout), U7.1 (VCC)
/3.3V: J3.1, U1.1 (1.2-3.6V)
/RX: J3.3, R3.1, U1.6 (A5)
/TX: J3.2, U1.4 (A3)
GND2: C5.2, C6.2, H4.1, J1.1, J3.4, R3.2, U1.11 (GND), U6.4 (-Vout), U7.2 (GND)
GND 12: C1.2, D3.2 (A2), J2.4, U4.1 (In-)
unnamed: C1.1, D1.1 (K), D3.1 (A1), U4.2 (In+)
unnamed: R1.2, U1.17 (B3), U7.4 (TX)
unnamed: U1.15 (B5), U7.3 (RX)
unnamed: R2.2, U1.10 (OE)
unnamed: U4.3 (Out+), U6.1 (+Vin)
unnamed: U4.4 (Out-), U6.2 (-Vin)
RX+: J2.6, U7.6 (Z,RX+)
RX-: J2.3, U7.5 (Y,RX-)
TX+: J2.2, U7.7 (B,TX+)
TX-: J2.5, U7.8 (A,TX-)

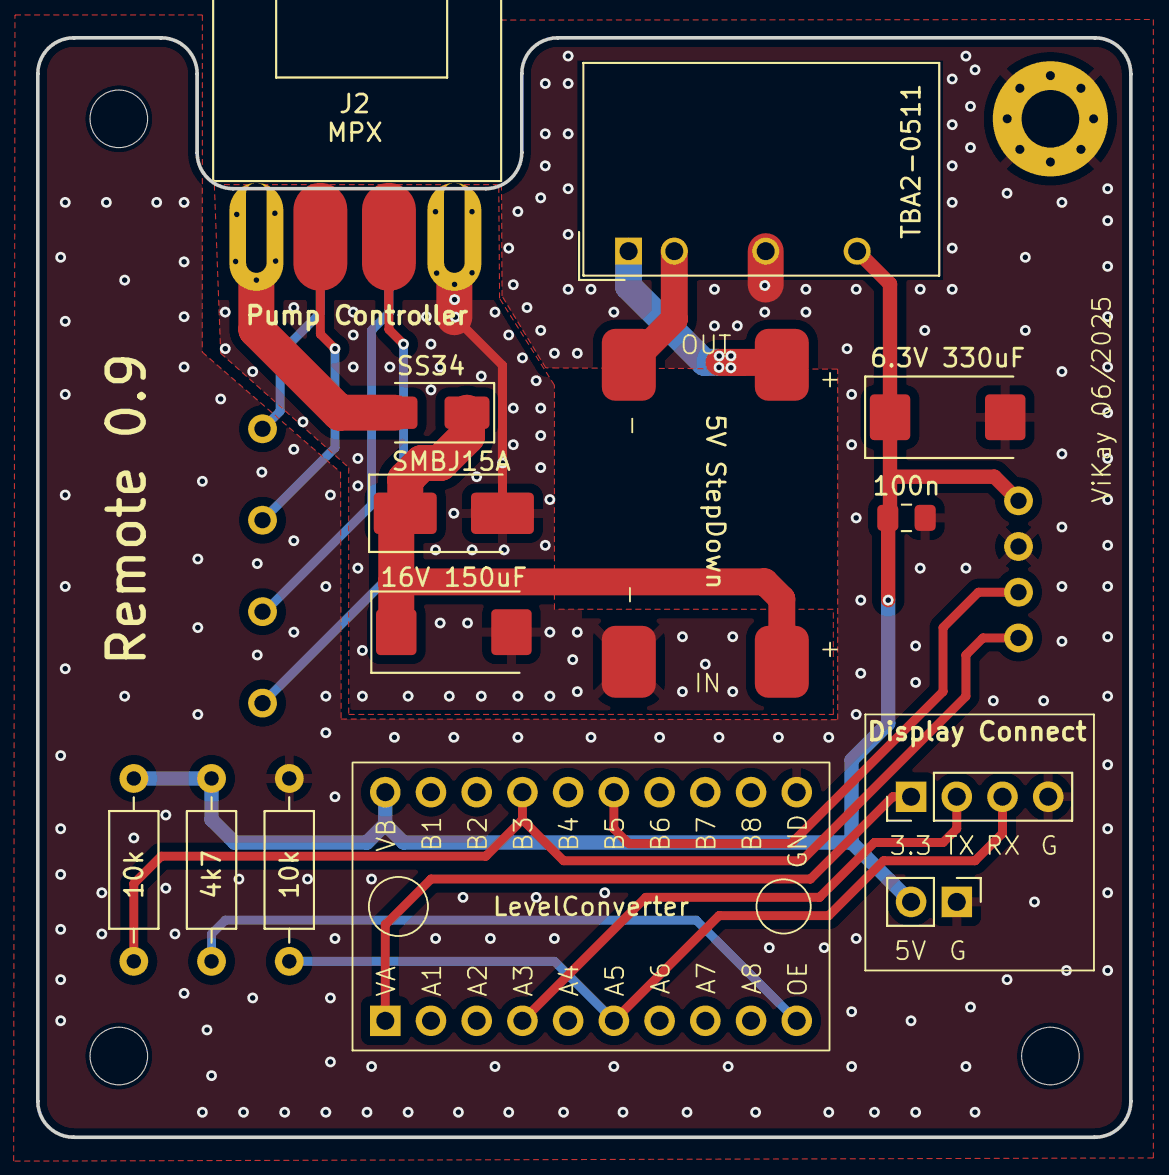
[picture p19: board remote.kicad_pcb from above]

Board: 2 copper layers, 60.7 x 61.1 mm, 19 parts (1 on the bottom side), 17 nets.

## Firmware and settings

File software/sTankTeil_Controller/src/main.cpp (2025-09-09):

/*
 * Hauptprogramm zur Steuerung einer Arduino-basierten Tanklösung
 *
 * Copyright (C) 2025 V0giK
 *
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
 * You should have received a copy of the GNU General Public License
 * along with this program.  If not, see <https://www.gnu.org/licenses/>.
 */

 #include <Arduino.h>

#include "variables.h"
#include "defines.h"
#include "main.h"
#include "bufferFunctions.h"
#include "pumpFunctions.h"


// Batteriespannung Warnungen - Callback-Funktion
void voltageAlert(const char* message, unsigned long duration) {
    // Serial.print(message);
    // Serial.print(" for ");
    // Serial.print(duration);
    // Serial.println(" seconds");

    if(strcmp(message, "warning") == 0) {
      if(duration >= 5) {
        buzzer.playBatteryLowTone();
        ledController.startLowBatteryBlinking();
      }

    } else {
      if(duration >= 5) {
        buzzer.playBatteryEmptyTone();
        ledController.startErrorBlinking();
        if(!(pump.isOn() || pumpSeq.isProcessing()) && bRemoteConnected) {
          // TODO: Spannung abschalten!!!!!
          //Serial.println("Power OFF.  empty battery");
          remoteCom.sendData('W', COM_ID_MC_RESET, "99", true);
          // delay(50);
          // resetFunc();
          // enterSleepNano();
        }
      } else {
        buzzer.playBatteryLowTone();
        ledController.stopLowBatteryBlinking();
      }
    }
}


void setup() {

  pinMode(PIN_LED_MODEL, OUTPUT);   // LED model
  pinMode(PIN_LED_MANUEL, OUTPUT);  // LED manuel
  // pinMode(PIN_LED_BATT, OUTPUT);    // LED batt. low
  pinMode(PIN_MOTE_TXRX, OUTPUT);
  digitalWrite(PIN_MOTE_TXRX, LOW);
  pinMode(PIN_MOTE_12V, OUTPUT);
  digitalWrite(PIN_MOTE_12V, LOW);

  // {
    // Serial.println("Lösche EEPROM...");
    // // EEPROM löschen
    // for (int i = 0; i < EEPROM.length(); i++) {
    //     EEPROM.write(i, 0xFF); // 0xFF entspricht einem leeren Wert
    // }
    // Serial.println("EEPROM wurde geleert.");
    // return;
  // }

  //configManager.resetToDefaults();

    #ifdef DEBUG
    Serial.begin(115200);        // Serielle Schnittstelle starten
    #endif
    // Callbacks registrieren
    remoteCom.setWriteCallback(onWrite);
    remoteCom.setReadCallback(onRead);

    bRemoteConnected = !digitalRead(PIN_MOTE_CHK);
    #ifdef DEBUG
    Serial.print("Remote connected (PIN_MOTE_CHK="); Serial.print(bRemoteConnected?"true":"false"); Serial.println(")");
    //Serial.flush();
    #endif

    if(bRemoteConnected) {
      digitalWrite(PIN_MOTE_TXRX, HIGH); // Versorgungsspannung für Kommunikation mit Remote aktivieren (RS422)
      digitalWrite(PIN_MOTE_12V, HIGH); // Versorgungsspannung für Remote aktivieren (12V)
      remoteCom.begin(9600);              // 19200 Serielle Schnittstelle mit der Remote initialisieren

    } else {
      buttonManager.begin(); // Initialisierung der Taster
      // Callbacks setzen
      buttonManager.onButtonInClick(onButtonInClick);
      buttonManager.onButtonOutClick(onButtonOutClick);
      buttonManager.onBothButtonsLongPress(onBothButtonsLongPress);

      // Modelldaten aus EEPROM lesen - falls vorhanden
      // Start immer im "Modell-Mode", ausser es sind keine Daten vorhanden ... dies auch beim Mode-Wechsel berücksichtigen!!!!!
      bHasModelSaved = model.loadFromEEPROM(EEPROM_ADR_MODEL);
      if(bHasModelSaved) {
        fifo_input_buffer.push(getRecDataObj(COM_ID_PUMP_MODE, "1")); // MODE_AUTO
      } else {
        // model.setTankType(0); // TankType initialisieren da laufend darauf geprüft wird
        fifo_input_buffer.push(getRecDataObj(COM_ID_PUMP_MODE, "0")); // MODE_MANUELL
      }
    }

    buzzer.begin(); // Buzzer initialisieren

    // Konfiguration laden
    configManager.loadConfig();
    buzzer.setReminderSeconds(configManager.getSystemabschaltungSekunden());
    buzzer.setActive(configManager.getSignaltonOn());

    // Durchflusssensor initialisieren
    flowSensor.begin();
    flowSensor.setCalibration(configManager.getImpulseProLiter());
    // Drucksensor initialisieren
    pressureSensor.setNumSamples(configManager.getAnzahlMesswerteMittelwert());
    pressureSensor.calibSensor();

    // Akkuspannung initialisieren
    // TODO: Wert fehlt noch im EEPROM !!!!!!!!!!!!!!!!!
    // voltReader.setCalibrationFactor(2.9183);
    voltReader.setCalibrationFactor(configManager.getBattKalibrierungsfaktor() / 10000.0);
    voltReader.setThresholds(configManager.getMinimalspannungAkku() / 10.0, 9.5, voltageAlert);

    #ifdef DEBUG
    Serial.println("System gestartet...");
    //Serial.flush();
    #endif


    // LEDs prüfen
    digitalWrite(PIN_LED_MODEL, HIGH);
    digitalWrite(PIN_LED_MANUEL, HIGH);
    digitalWrite(PIN_LED_BATT, HIGH);
    delay(1500);
    digitalWrite(PIN_LED_MODEL, LOW);
    digitalWrite(PIN_LED_MANUEL, LOW);
    digitalWrite(PIN_LED_BATT, LOW);

    pinMode(PIN_MOTE_CHK, INPUT);
    // pinMode(PIN_TASTER_IN, INPUT);
    // pinMode(PIN_TASTER_OUT, INPUT);


    // ESP32 (Remote) neu starten
    remoteCom.sendData('W', COM_ID_MC_RESET, "");

    buzzer.playAcknowledgmentTone();
}

void loop() {
  bool hasActivity = false;

  if(pump.isOn() || pumpSeq.isProcessing()) hasActivity = true;
  hasActivity |= remoteCom.tick();  // Remote prüfen
  buttonManager.update();           // Taster-Logik aktualisieren
  hasActivity |= buffer_tick();     // Eingangs-Puffer verarbeiten

  if(hasActivity) buzzer.updateActivity();
  buzzer.checkReminder();

  // Berechne die Spannung
  voltReader.readVoltage();
  // LED-Status aktualisieren
  ledController.update();


  unsigned long currentMillis = millis();
  if (currentMillis - lastMillis >= MEASUREMENT_INTERVAL) {
      lastMillis = currentMillis;
      bHalfIntervall = false;

      handleFlowMeasurement();     // Durchflussmessung
      handlePressureMeasurement(); // Druckmessung
      handlePumpSeq();

  }
  if (!bHalfIntervall && currentMillis - lastMillis >= MEASUREMENT_INTERVAL / 2) {
    bHalfIntervall = true;

    // Durchflussrate und Gesamtmenge berechnen
    if(pumpMode != MODE_CALIB_FLOW){
      flowSensor.tick();
    }
    // Druck abfragen
    pressureSensor.tick();

    // Remote an/ausgesteckt
    if(!digitalRead(PIN_MOTE_CHK) != bRemoteConnected) {
      resetNano();
    }

  }

  // 5 Sekunden
  if (currentMillis - lastMillis5sec >= INTERVAL_5S) {
    lastMillis5sec = currentMillis;
    // Batteriespannung prüfen
    voltReader.evaluateVoltage(); // Bewertung der Spannung und ggf. Callback-Aufruf
    remoteCom.sendData('W', COM_ID_AKKU_VOLT, voltReader.getLastVoltageString().c_str());

  }

}



// Durchflussmessung durchführen
void handleFlowMeasurement() {
  if(pump.isOn() || bSendBroadcast) {
    switch(pumpMode) {
      case MODE_CALIB_FLOW:
        // TODO
        remoteCom.sendData('W', COM_ID_FLOWCALIBRATE, String(flowSensor.getPulses()).c_str());
        return;
        break;
      // case MODE_AUTO:
      // case MODE_CALIB_MODEL:
      // case MODE_MANUELL:
      default:
        break;
    }

    // UART-Daten senden
    remoteCom.sendData('W', COM_ID_CURRENT_ML, String(flowSensor.getTotalMilliliters()).c_str());

    // Debug-Ausgabe
    // if (DEBUG) {
    //   Serial.print("Durchflussrate: ");
    //   Serial.print(flowSensor.getFlowRate());
    //   Serial.print(" ml/s, Gesamtmenge: ");
    //   Serial.print(flowSensor.getTotalMilliliters());
    //   Serial.println(" ml");
    // }

  }
}

// Druckmessung durchführen
void handlePressureMeasurement() {

  double pressure_mbar = floor(pressureSensor.getPressureMbar(true));
  double pressure_diff = floor(pressureSensor.getDiffMbar());
  if(pump.isOn() || bSendBroadcast) {
    remoteCom.sendData('W', COM_ID_CURRENT_MBAR, String(pressure_mbar).c_str());
    remoteCom.sendData('W', COM_ID_CURRENT_DIFF_MBAR, String(pressure_diff).c_str());

    // Debug-Ausgabe
    // if (DEBUG) {
    //     Serial.print("Druck: ");
    //     Serial.print(pressure_mbar, 2);
    //     Serial.print(" mbar, Diff: ");
    //     Serial.print(pressure_diff, 2);
    //     Serial.println(" mbar");
    // }
  }

}

// Callback für SW (Schreiben)
void onWrite(int16_t id, const String &value) {
  // if (DEBUG) Serial.println("SW erhalten: ID=" + String(id) + ", Wert=" + value);

  recData dta = getRecDataObj(id, value);
  // in Input-Puffer schreiben
  fifo_input_buffer.push(dta);
}

// Callback für SR (Lesen)
void onRead(int16_t id) {
  // if (DEBUG) Serial.println("SR erhalten: ID=" + String(id));

  bool hasActivity = true;
  switch (id) {
    case COM_ID_TYPE:
      remoteCom.sendData('W', id, HARDWARE_TYPE);
      break;
    case COM_ID_FLOW_TICKS:
      remoteCom.sendData('W', id, String(configManager.getImpulseProLiter()).c_str());
      break;
    case COM_ID_PRESSURE_AVG:
      remoteCom.sendData('W', id, String(configManager.getAnzahlMesswerteMittelwert()).c_str());
      break;
    case COM_ID_AKKU_MIN:
      remoteCom.sendData('W', id, String(configManager.getMinimalspannungAkku()).c_str());
      break;
    case COM_ID_AKKU_CALIB:
      remoteCom.sendData('W', id, String(configManager.getBattKalibrierungsfaktor()).c_str());
      break;
    case COM_ID_BEEP:
      remoteCom.sendData('W', id, String(configManager.getSignaltonOn()).c_str());
      break;
    case COM_ID_PWR_MANUEL:
      remoteCom.sendData('W', id, String(configManager.getManuellePumpenleistung()).c_str());
      break;
    case COM_ID_SYSTEM_OFF:
      remoteCom.sendData('W', id, String(configManager.getSystemabschaltungSekunden()).c_str());
      break;
    case COM_ID_FIRMWARE_VERSION:
      remoteCom.sendData('W', id, SW_VERSION);
      break;
    default:
      //
      hasActivity = false;
      break;
  }

  if(hasActivity) buzzer.updateActivity();
}




void handlePumpSeq() {
  refuellAction();
  backfuellAction();
  defuellAction();
  airremovalAction();
}






// Callback-Funktionen definieren
void onButtonInClick() {
  buzzer.playAcknowledgmentTone();
  if(pump.isOn()) {
    fifo_input_buffer.push(getRecDataObj(COM_ID_PUMP_CONTROL, "2")); // CTR_STOP
  } else {
    fifo_input_buffer.push(getRecDataObj(COM_ID_PUMP_CONTROL, "1")); // CTR_TANKEN
  }
}

void onButtonOutClick() {
  buzzer.playAcknowledgmentTone();
  if(pump.isOn()) {
    fifo_input_buffer.push(getRecDataObj(COM_ID_PUMP_CONTROL, "2")); // CTR_STOP
  } else {
    fifo_input_buffer.push(getRecDataObj(COM_ID_PUMP_CONTROL, "0")); // CTR_ENTTANKEN
  }
}

void onBothButtonsLongPress() {
  buzzer.playAcknowledgmentTone();
  if(pump.isOn()) {
    fifo_input_buffer.push(getRecDataObj(COM_ID_PUMP_CONTROL, "2")); // CTR_STOP
  }
  if(bHasModelSaved && pumpMode == MODE_MANUELL) {
    fifo_input_buffer.push(getRecDataObj(COM_ID_PUMP_MODE, "1")); // MODE_AUTO
  } else {
    if(!bHasModelSaved) buzzer.playNegativeTone();
    fifo_input_buffer.push(getRecDataObj(COM_ID_PUMP_MODE, "0")); // MODE_MANUELL
  }
}

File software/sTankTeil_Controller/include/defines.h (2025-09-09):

/*
 * Hauptprogramm zur Steuerung einer Arduino-basierten Tanklösung
 *
 * Copyright (C) 2025 V0giK
 *
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
 * You should have received a copy of the GNU General Public License
 * along with this program.  If not, see <https://www.gnu.org/licenses/>.
 */

#pragma once

// 16 Bit
#define INT_BIT_LENGTH 15

// prüfen/ setzen des ACK Bit's für die Srrielle Kommunikation
#define isacki(value) (((value) >> (INT_BIT_LENGTH)) & 0x01)
#define acki(value) ((value) |= (1UL << (INT_BIT_LENGTH)))
#define nacki(value) ((value) &= ~(1UL << (INT_BIT_LENGTH)))
#define setacki(value, wack) ((wack)?(acki(value)):(nacki(value)))
#define clracki(value) ((nacki(value)))


#define TYPE_PUMP "1"

#define HARDWARE_TYPE TYPE_PUMP

#define PIN_MOTE_12V 2
#define PIN_MOTE_TXRX 13
#define PIN_SOFT_RX 11
#define PIN_SOFT_TX 10

#define PIN_PUMP_D0 5
#define PIN_PUMP_D1 6

#define PIN_FLOW 3
#define PIN_PRESSURE A6

#define PIN_BATT_MESURE A0
#define PIN_LED_MODEL   A1
#define PIN_LED_MANUEL  A2
#define PIN_LED_BATT    9
#define PIN_TASTER_IN   7
#define PIN_TASTER_OUT  8
#define PIN_MOTE_CHK    12
#define PIN_BUZZER 4


// UART Nachrichten IDs
#define COM_ID_TYPE                           1
#define COM_ID_FLOW_TICKS                     2
#define COM_ID_PRESSURE_AVG                   3
#define COM_ID_AKKU_MIN                       4
#define COM_ID_AKKU_CALIB                     5
#define COM_ID_BEEP                           6
#define COM_ID_SYSTEM_OFF                     7
#define COM_ID_PWR_MANUEL                     8
#define COM_ID_PUMP_PWR                       9
#define COM_ID_MAX_REFUEL_TIME                10
#define COM_ID_MAX_DEFUEL_TIME                11
#define COM_ID_BACK_FUEL_TIME                 12
#define COM_ID_AIR_REMOVAL_TIME               13
#define COM_ID_PUMP_STOP_EMPTY_DELAY          14
#define COM_ID_MESSUREMENT_DELAY              15
#define COM_ID_MAX_REFUEL_ML                  16
#define COM_ID_MAX_DEFUEL_ML                  17
#define COM_ID_MAX_PRESSURE                   18
#define COM_ID_PUMP_STOP_PRESSURE_DIFF        19
#define COM_ID_PUMP_STOP_PRESSURE_EMPTY       20
#define COM_ID_HOPPER_PRESSURE                21
#define COM_ID_PUMP_STOP_HOPPER_PRESSURE_DIFF 22
#define COM_ID_PRESSURE_DROP_HOSE_BREAK       23

#define COM_ID_SAVE_MODEL_EEPROM              29

#define COM_ID_STATUS                         30
#define COM_ID_CURRENT_ML                     31
#define COM_ID_CURRENT_MBAR                   32
#define COM_ID_CURRENT_DIFF_MBAR              33
#define COM_ID_AKKU_VOLT                      34

#define COM_ID_PUMP_CONTROL                   40
#define COM_ID_WRITE_EEPROM                   41
#define COM_ID_PUMP_MODE                      42
#define COM_ID_FLOWCALIBRATE                  43
#define COM_ID_TANKTYPE                       44
#define COM_ID_BROADCAST                      45
#define COM_ID_FIRMWARE_VERSION               46

#define COM_ID_MC_RESET                       99

// Pumpmodes
#define MODE_MANUELL     0
#define MODE_AUTO        1
#define MODE_CALIB_FLOW  2
#define MODE_CALIB_MODEL 3

// Tanktype
#define TANK_BEUTEL 0
#define TANK_1TANK  1
#define TANK_2TANK  2

// Pumpaktionen
#define CTR_ENTTANKEN 0
#define CTR_TANKEN    1
#define CTR_STOP      2


//
#define REFUELL_BEUTEL     "1,2,1,4"
#define DEFUELL_BEUTEL     "3"
#define REFUELL_1TANK      "1,4"
#define DEFUELL_1TANK      "3"
#define REFUELL_2TANKS     "1,5,4"
#define DEFUELL_2TANKS     "3"

#define SW_VERSION "1.0.1"

// Debug switch für compile-time
// #define DEBUG

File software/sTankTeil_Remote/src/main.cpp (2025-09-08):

/*
 * Hauptprogramm zur Steuerung einer Arduino-basierten Tanklösung
 *
 * Copyright (C) 2025 V0giK
 *
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
 * You should have received a copy of the GNU General Public License
 * along with this program.  If not, see <https://www.gnu.org/licenses/>.
 */

#include <Arduino.h>
#include <ArduinoJson.h>
#include <LittleFS.h>  // Für den Dateizugriff
#include "main.h"
// #include <lvgl.h>
// #include "lovyanGfxSetup.h"
#include "ui/ui.h"
#include "ui/vars.h"
#include "ui/styles.h"
#include "ui/actions.h"
#include "helper.h"
#include "uartCommunication.h"
#include "modelParameters.h"
#include "snakeGame.h"
#include "aeroBlocks.h"  // Include the AeroBlocks header
#include <esp_task_wdt.h>
#include "configManager.h" // Include the config manager
#include "modelManager.h" // Include the model manager
#include "controllerUtils.h" // Include the controller utility functions
#include "uiHandlers.h" // <--- Neues Include für die ausgelagerte Funktion
#include "displayConfig.h" // LVGL Display-Konfiguration
#include "pumpControl.h" // Pumpensteuerung
#include "inputHandlers.h" // Neue Includes für die Input Handler
#include <WiFi.h>
#include <esp_bt.h>

// Konstanten für optimale Timing-Intervalle
const uint32_t UART_CHECK_INTERVAL = 10;     // 100Hz für UART
const uint32_t UI_UPDATE_INTERVAL = 20;      // 50Hz für Display
const uint32_t STATUS_CHECK_INTERVAL = 1000; // 1Hz für System Status
const uint32_t WDT_TIMEOUT = 5;              // 5s Watchdog

// Timing Variablen
static uint32_t lastUartCheck = 0;
static uint32_t lastUiUpdate = 0;
static uint32_t lastStatusCheck = 0;

// Debug-Ausgabe steuern
const bool DEBUG = false;
//LV_LOG_USER("dfg");

// Setup constants
const int UI_UPDATE_ITERATIONS = 5;
const int MODEL_JSON_DOC_SIZE = 1024;  // Increased from 512 to 1024 bytes to handle larger model files
const int SETUP_DISPLAY_DELAY = 100;  // ms

// Display
LGFX tft;

extern lv_event_t g_keyboardShowE;
extern lv_event_t g_numpadShowE;
extern lv_event_t g_go2settingsModelsE;
extern lv_event_t g_resetDataFieldsE;
extern lv_event_t g_go2modelE;
extern lv_event_t g_go2calibrateModelE;
extern lv_event_t g_eventButtonClickE;
extern lv_event_t g_changePumpPwrE;
extern lv_event_t g_go2newModelE;


// Define the global variables that replace the bit fields for the undefined references
// Note: Some flags are now in the UIFlags union - separate bools removed for consistency

volatile UIFlags g_uiflags = {0};  // Init all to 0

lv_obj_t *objModelPlus = NULL;
lv_obj_t *objLoadedModel = NULL;

bool bSaveOnUnload = true; // Werte beim verlassen der Page speichern

// Pfad zur JSON-Konfigurationsdatei
const char *configFilePath = "/config.json";

// Globale Konfigurationsdaten
Config config;

// Modell Daten
ModelParameters model;

// UART-Kommunikation
UartCommunication uartCom(17, 18, DEBUG, 2); // RX = GPIO19, TX = GPIO20

// Snake
SnakeGame snakeGame;
// AeroBlocks
AeroBlocks aeroBlocks;

// Add missing error state flag
bool inControllerErrorState = false;

// Backup mode flags
volatile bool inBackupMode = false;
volatile bool otaCompletedFlag = false;

volatile bool g_modelLoadPending = false;
int g_modelLoadId = 0;



void printSystemSettings() {
  if(DEBUG) {
    // Load Config in Variables
    Serial.println("Owner:                " + String(get_var_s_owner()));
    Serial.println("Load last model:      " + String(get_var_b_load_last_model()));
    Serial.println("Signalton:            " + String(get_var_b_signal()));
    Serial.println("Flow Ticks:           " + String(get_var_s_flow_ticks()));
    Serial.println("Flow Messungen AVG:   " + String(get_var_s_pressure_avg()));
    Serial.println("Akku min. V:          " + String(get_var_s_akku_min_v()));
    // Variable für config.akkuFactor fehlt noch!
    Serial.println("System idle off:      " + String(get_var_s_sys_power_off_time()));
    Serial.println("PWR manuell:          " + String(get_var_s_pump_pwr_manu()));
    Serial.println("PWR Calib:            " + String(get_var_s_pump_pwr_calib()));
    Serial.println();
  }
}

void setup() {
    // Disable WiFi and Bluetooth to ensure they are not active
    WiFi.mode(WIFI_OFF);
    WiFi.disconnect(true);
    btStop();

    // Initialize serial communication first
    Serial.begin(115200);
    uartCom.begin(9600); // 19200

    if(DEBUG) Serial.println("Starting initialization...");

    // Display and touch setup
    lvglSetup();
    ui_init();

    // Initial values
    setInitialValues();
    
    // Initialize filesystem
    if (!initializeFileSystem()) {
        showErrorAndSleep("File system error");
        return;
    }
    
    // Update display to show progress
    updateDisplay(UI_UPDATE_ITERATIONS);

    // Load configuration
    loadConfigWithDefaults(config, configFilePath);
    applyConfigToUI(config);
    
    if(DEBUG) printSystemSettings(config);

    // Connect to controller - this can take up to 15 seconds
    bool controllerConnected = searchAndLoadController();
    
    // Initialize watchdog AFTER controller search to prevent timeouts
    esp_task_wdt_init(WDT_TIMEOUT, true);
    esp_task_wdt_add(NULL);
    
    if (!controllerConnected) {
        handleControllerError();
        return;
    }
    
    // Load model data
    if(DEBUG) Serial.println("Loading models...");
    set_var_s_status("Loading models...");
    
    loadModelsFromStorage();
    
    // Display final status of model loading
    if(DEBUG) {
        if(objModelPlus != NULL) {
            Serial.println("Model loader completed successfully");
        } else {
            Serial.println("WARNING: Model loader failed to create the + button");
        }
    }
    
    updateDisplay(10); // More UI updates to ensure models display
    set_var_s_status("");

    // Navigate to appropriate screen
    navigateToInitialScreen();
    
    if(DEBUG) Serial.println("Initialization complete");
}

// Dateisystem initialisieren
bool initializeFileSystem() {
    if (!LittleFS.begin()) {
        if(DEBUG) Serial.println("LittleFS could not be initialized!");
        return false;
    }
    return true;
}

// Controller error handling
void handleControllerError() {
    if(DEBUG) Serial.println("Controller not found or communication error");
    
    // Display error message
    set_var_s_status("Controller not found");
    set_var_b_hide_box_start_error(false);
    
    // Set flag to indicate we're in error state instead of entering infinite loop
    inControllerErrorState = true;
    
    // Update display to ensure the error message is visible
    for(int i = 0; i < 20; i++) {
        lv_timer_handler(); // Use only lv_timer_handler() for LVGL 9.x
        ui_tick();
        delay(10);
    }
}

// Navigate to initial screen based on config
void navigateToInitialScreen() {
    // Go to last model or home screen
    if(config.lastModel > 0) {
        UI_SET_GO2MODEL();
    } else {
        UI_SET_GO2HOME();
    }
}
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

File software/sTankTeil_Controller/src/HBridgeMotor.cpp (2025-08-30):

#include <Arduino.h>
#include "HBridgeMotor.h"

#define MIN_PWR 40

/**
 * Konstruktor für den HBridgeMotor
 * @param pin1 Pin 1 des Motors
 * @param pin2 Pin 2 des Motors
 */
HBridgeMotor::HBridgeMotor(int pin1, int pin2) {
    this->pin1 = pin1;
    this->pin2 = pin2;
    this->currentSpeed = 0;
    this->isForward = true;

    pinMode(pin1, OUTPUT);
    pinMode(pin2, OUTPUT);
}

/**
 * Setzt die Geschwindigkeit des Motors (ohne Starten)
 * @param percent Der gewünschte Geschwindigkeitswert in Prozent (0-100)
 */
void HBridgeMotor::setSpeed(int percent) {
    percent = constrain(percent, 0, 100);  // Prozentwert auf 0-100 begrenzen
    currentSpeed = map(percent, 0, 100, 0, 255);  // Prozent in PWM-Wert umwandeln
}

/**
 * Startet den Motor vorwärts mit Sanftanlauf
 * @param rampTime Die Zeit, die für den Sanftanlauf benötigt wird
 */
void HBridgeMotor::startForward(int rampTime) {
    int initialSpeed = 0;
    for (int speed = initialSpeed; speed <= currentSpeed; speed++) {
        analogWrite(pin1, speed);  // HIGH/PWM
        digitalWrite(pin2, LOW);   // LOW
        delay(rampTime / currentSpeed);  // Zeitintervall für die Rampe
    }
    isForward = true;
    isRunning = true;
}

/**
 * Startet den Motor rückwärts mit Sanftanlauf
 * @param rampTime Die Zeit, die für den Sanftanlauf benötigt wird
 */
void HBridgeMotor::startBackward(int rampTime) {
    int initialSpeed = 0;
    for (int speed = initialSpeed; speed <= currentSpeed; speed++) {
        digitalWrite(pin1, LOW);  // LOW
        analogWrite(pin2, speed); // HIGH/PWM
        delay(rampTime / currentSpeed);  // Zeitintervall für die Rampe
    }
    isForward = false;
    isRunning = true;
}

/**
 * Startet den Motor vorwärts mit Sanftanlauf
 * @param targetPercent Der Zielwert für die Geschwindigkeit in Prozent (0-100)
 * @param rampTime Die Zeit, die für den Sanftanlauf benötigt wird
 */
void HBridgeMotor::forwardRamp(int targetPercent, int rampTime) {
    targetPercent = constrain(targetPercent, MIN_PWR, 100);  // Zielprozentwert auf 35-100 begrenzen
    int targetSpeed = map(targetPercent, 0, 100, 0, 255);  // Zielprozent in PWM-Wert umwandeln

    if(currentSpeed == 0) {
        currentSpeed = map(MIN_PWR, 0, 100, 0, 255);
    }
    for (int speed = currentSpeed; speed <= targetSpeed; speed++) {
        analogWrite(pin1, speed);  // HIGH/PWM
        digitalWrite(pin2, LOW);   // LOW
        delay(rampTime / (targetSpeed - currentSpeed));  // Zeitintervall für die Rampe
    }
    currentSpeed = targetSpeed;
    isForward = true;
    isRunning = true;
}

/**
 * Startet den Motor rückwärts mit Sanftanlauf
 * @param targetPercent Der Zielwert für die Geschwindigkeit in Prozent (0-100)
 * @param rampTime Die Zeit, die für den Sanftanlauf benötigt wird
 */
void HBridgeMotor::backwardRamp(int targetPercent, int rampTime) {
    targetPercent = constrain(targetPercent, MIN_PWR, 100);  // Zielprozentwert auf 35-100 begrenzen
    int targetSpeed = map(targetPercent, 0, 100, 0, 255);  // Zielprozent in PWM-Wert umwandeln

    if(currentSpeed == 0) {
        currentSpeed = map(MIN_PWR, 0, 100, 0, 255);
    }
    for (int speed = currentSpeed; speed <= targetSpeed; speed++) {
        digitalWrite(pin1, LOW);  // LOW
        analogWrite(pin2, speed); // HIGH/PWM
        delay(rampTime / (targetSpeed - currentSpeed));  // Zeitintervall für die Rampe
    }
    currentSpeed = targetSpeed;
    isForward = false;
    isRunning = true;
}

/**
 * Passt die Geschwindigkeit des Motors während der Bewegung an
 * @param percent Der gewünschte Geschwindigkeitswert in Prozent (0-100)
 */
void HBridgeMotor::adjustSpeed(int percent) {
    percent = constrain(percent, MIN_PWR, 100);  // Prozentwert auf 0-100 begrenzen
    int newSpeed = map(percent, 0, 100, 0, 255);  // Prozent in PWM-Wert umwandeln

    if (isForward) {
        analogWrite(pin1, newSpeed);  // HIGH/PWM
        digitalWrite(pin2, LOW);     // LOW
    } else {
        digitalWrite(pin1, LOW);    // LOW
        analogWrite(pin2, newSpeed); // HIGH/PWM
    }

    currentSpeed = newSpeed;
}

/**
 * Startet den Motor vorwärts mit der angegebenen Geschwindigkeit
 * @param percent Der gewünschte Geschwindigkeitswert in Prozent (0-100)
 */
void HBridgeMotor::forward(int percent) {
    percent = constrain(percent, MIN_PWR, 100);  // Prozentwert auf 0-100 begrenzen
    int speed = map(percent, 0, 100, 0, 255);  // Prozent in PWM-Wert umwandeln
    analogWrite(pin1, speed);  // HIGH/PWM
    digitalWrite(pin2, LOW);   // LOW
    currentSpeed = speed;
    isForward = true;
    isRunning = true;
}

/**
 * Startet den Motor rückwärts mit der angegebenen Geschwindigkeit
 * @param percent Der gewünschte Geschwindigkeitswert in Prozent (0-100)
 */
void HBridgeMotor::backward(int percent) {
    percent = constrain(percent, MIN_PWR, 100);  // Prozentwert auf 0-100 begrenzen
    int speed = map(percent, 0, 100, 0, 255);  // Prozent in PWM-Wert umwandeln
    digitalWrite(pin1, LOW);  // LOW
    analogWrite(pin2, speed); // HIGH/PWM
    currentSpeed = speed;
    isForward = false;
    isRunning = true;
}

/**
 * Motor anhalten (freilaufend)
 */
void HBridgeMotor::stop() {
    digitalWrite(pin1, LOW);  // LOW
    digitalWrite(pin2, LOW);  // LOW
    currentSpeed = 0;
    isRunning = false;
}

/**
 *  Motor bremsen 
 */
void HBridgeMotor::brake() {
    digitalWrite(pin1, HIGH);  // HIGH
    digitalWrite(pin2, HIGH);  // HIGH
    currentSpeed = 0;
    isRunning = false;
}

/**
 * Überprüft, ob der Motor läuft
 * @return true, wenn der Motor läuft, andernfalls false
 */
bool HBridgeMotor::isOn() {
    return isRunning;
}

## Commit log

2025-08-14 Add existing PlatformIO and KiCad data
    [pump_controller.kicad_pcb, pump_controller.kicad_sch, pump_controller.step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]
2025-08-14 KiCad clean
    [arduino.kicad_sch, pump_controller.kicad_sch]
2025-08-15 code cleanup, tiny fixes
    [HBridgeMotor.cpp, SystemConfigManager.cpp, bufferFunctions.cpp]
2025-08-16 Serlial.print's entfernt
2025-08-16 uart opimierung
2025-08-17 kicad gerber files
    [bom.csv, designators.csv, positions.csv]
2025-08-27 refactor: Codestruktur verbessert für bessere Übersichtlichkeit und Wartbarkeit
2025-08-30 refactor style
    [UART_Protokoll.ods]
2025-08-31 feat: version inf
    [UART_Protokoll.ods]
2025-09-01 style: kringel
    [UART_Protokoll.ods]
2025-09-06 Add image pump_fertig.jpg to README
2025-09-08 feat: add Druck and Diff. Druck labels to pump screen and update their values
2025-09-08 Refactor/refactor (#7)
    * refactor: LVGL Memory, PSRAM, LVGL-Caches, LVGL Refresh-Rate, Draw Layer Buffer, Modell-UI-Elemente begrenzen
    * fix: disable debug output for cleaner execution
    * refactor: consolidate UI flags into a union for improved maintainability and consistency
    [configManager.cpp, main.cpp, pumpControl.cpp]
2025-09-08 fix: fix backup mode with OTA support and related flags (#8)
    [main.cpp]
2025-09-09 Refactor/comtroller (#11)
    * refactor: update PumpSequence to use fixed-size array and simplify constructor; modify buffer functions for better memory handling; update software version to 1.0.1
    * refactor: remove debug flag from UartCommunication constructor; increase buffer size in recData struct; update debug output handling across multiple files
    * refactor: streamline loop logic for activity detection and update LED status
    [ModelParameters.cpp, PumpSequence.cpp, SystemConfigManager.cpp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]
2026-10-18 Release v1.1.0: EEPROM-Modellbug-Fix + Versionsharmonisierung
    Modell wurde beim ersten Boot nach dem Flashen erkannt, beim Neustart
    jedoch nicht mehr (Daten schienen verloren). Drei zusammenhängende Bugs:
    - EEPROM / CRC (helper.cpp, helper.h):
    calculateCRC brach bei Nullbytes im Modellnamen ab (internes strlen).
    Eingefuehrte ueberladene Variante calculateCRC(const char*, size_t);
    alte Signatur bleibt als Wrapper fuer UART-Kommunikation erhalten.
    - ModelParameters.h/cpp:
    MODEL_DATA_SIZE von 55 (15 + 20*2) auf 49 (15 + 17*2) korrigiert.
    calcCkecksum nutzt jetzt die length-Variante mit MODEL_DATA_SIZE.
    - variables.h:
    EEPROM_ADR_MODEL von 13 auf 100 verschoben. SystemConfig beleg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
2026-10-18 chore: .gitignore fuer Release-Artefakte und IDE-Configs
    Verhindert versehentliches Einchecken der bei lokalen Release-Builds
    erzeugten Ordner (release-*/) und der persoenlichen VS-Code-Konfigs
    (.vscode/).

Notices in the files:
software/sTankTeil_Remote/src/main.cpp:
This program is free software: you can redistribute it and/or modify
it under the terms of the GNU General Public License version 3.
